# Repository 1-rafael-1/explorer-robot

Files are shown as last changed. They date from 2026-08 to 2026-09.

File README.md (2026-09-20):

# explorer-robot

Evolving project for a tracked robot platform with LiDAR-based
autonomous navigation and sensor-driven obstacle avoidance.

Built in Rust on [Embassy](https://embassy.dev/) for the RP2350 microcontroller.
This iteration builds on hardware experience from [simple-robot](https://github.com/1-rafael-1/simple-robot), adding a
360° spinning LiDAR (COIN-D6), a VL53L0X rangefinder (front-down), ICM-20948 IMU over
SPI, a ST7789 TFT display, and a Grove Vision AI V2 camera module — as much as I can manage on custom PCB hardware. The ultrasonic/servo sweeping sensor array is ditched, and so are the IR sensors.

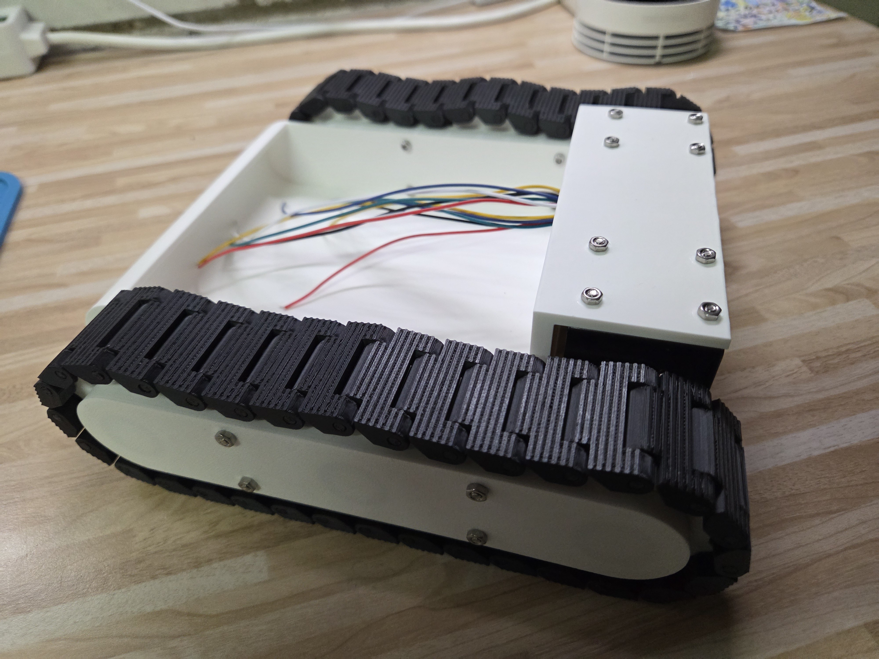
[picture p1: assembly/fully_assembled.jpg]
Fully assembled explorer-robot


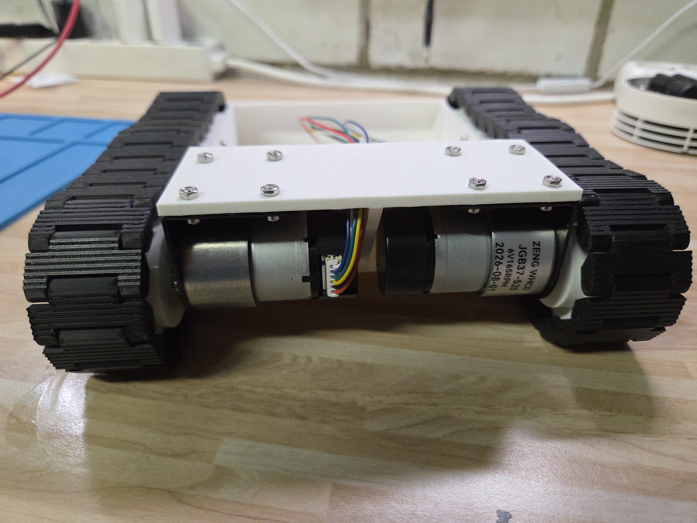
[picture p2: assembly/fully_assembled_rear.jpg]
Fully assembled explorer-robot, rear view


## Status

Active development. Core subsystems (drive, perception, UI, calibration) are
implemented: the LiDAR driver and the Panel and Touch Panel geometry are real,
while the rangefinder and the AI camera remain stubbed or planned.

The big to-dos, in no particular order:

- [x] Make a new chassis to accommodate the new motors and ball bearings.
- [x] Make a D6 lidar driver
- [x] Make an async tft driver
- [x] Integrate the D6 lidar driver into the firmware
- [x] Integrate the tft driver into the firmware
- [ ] Make an async-capable VL53L0X driver and integrate that
- [ ] Make a new schematic adapting from simple-robot
- [ ] Full breadboard demonstrator to see if the firmware is botched
- [ ] Make an async Grove Vision AI V2 driver and integrate that
- [ ] Design a new PCB from that. Depending on how mad I feel, maybe ditch some dev boards in favor of an SMD design.

## Hardware

- **MCU:** Raspberry Pi RP2350B (dual-core Cortex-M33)
- **Motors:** 2× JGB37-520 6V DC with Hall encoders, 165 RPM
- **Bearings:** 12× 6802-2RS (DIN 625; a.k.a. 61802-2RS)
- **Motor driver:** TB6612FNG dual H-bridge
- **LiDAR:** COIN-D6 360° spinning dTOF (core1, buffered UART0 [] power MOSFET, driver integrated, off at boot and powered on demand)
- **AI Cam:** Grove Vision AI V2 (core0, UART1 [] power MOSFET reserved, not yet integrated)
- **Rangefinder:** 1× VL53L0X ToF, front-down (stair/drop detection), on shared I2C0 bus (currently stubbed)
- **IMU:** ICM-20948 9-axis over dedicated SPI bus
- **Display:** ST7789 240×320 Panel driven landscape as a 320×240 framebuffer, on the shared SPI1 bus
- **Input:** Resistive touch panel (XPT2046-class) sharing the display's SPI1 bus
- **Power:** 2S LiPo (8.4V max)

## Assembly

The chassis and running gear are my first CAD design at this level of
complexity. It works as I planned, but I fully expect to find reasons to change,
add, or remove parts as I go. I've printed it in PLA on a 0.4 mm nozzle at
variable layer height with good results — after running the motors for an hour
straight on a riser, nothing looked worn or abraded, there was no PLA dust
anywhere, and all the track pins were still in place.

### Parts required

Purchased:

- 2× JGB37-520 motors (with encoders)
- 2× matching motor brackets (often sold with the motors)
- 12× 6802-2RS ball bearings (6 per track)
- 8× M3 8 mm screws
- 8× M3 40 mm screws
- 16× M3 nuts

Printed:

- 1× chassis main part
- 2× inner track pod parts
- 2× outer track pod parts
- 2× driven sprockets
- 4× freewheeling sprockets
- 6× sprocket holders (one per sprocket)
- 64× track links (32 per track)
- 64× track link pins

### Track assembly

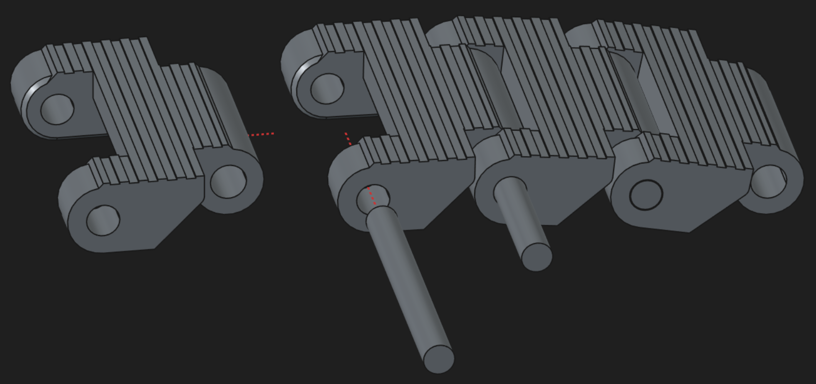
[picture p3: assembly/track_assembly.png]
Track assembly


### Track pod assembly

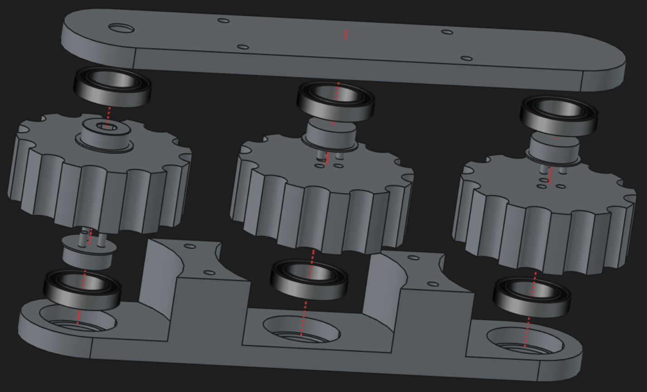
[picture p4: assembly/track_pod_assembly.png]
Track pod assembly


### Overall assembly

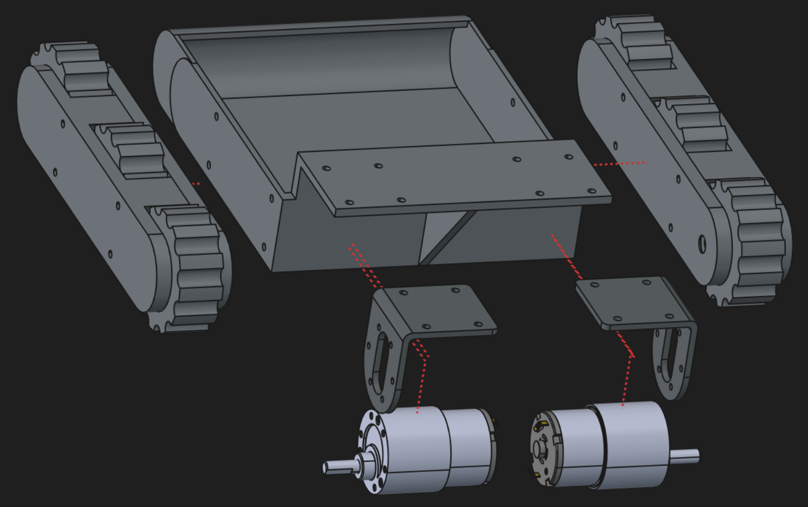
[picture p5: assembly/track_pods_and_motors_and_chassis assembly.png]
Track pods, motors and chassis


### Assembly tips

- The driven sprocket's D-shaft hole is a very tight fit on the motor's D-shaft.
  Push the sprocket onto the shaft at least once before final assembly — the real
  assembly later will be much easier.
- The bearings have to be pressed into the pod shells with some force. Keep them
  even, since everything is a tight fit. I used a rubber mallet, gently.
- After each step, check that the sprockets turn freely in the pod without
  scraping. The screws — combined with the pressure needed to fit the D-shaft —
  can introduce enough strain that something ends up slightly off, causing wobble
  and scraping. It does fit in the end, but takes a little patience.
- The 8 mm screws can be fiddly to get in — use tweezers. After a few minutes of
  colorful cursing they'll go in.

## License

MIT

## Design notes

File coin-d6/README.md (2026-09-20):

# coin-d6

An async driver for the COIN-D6 360° spinning dToF LiDAR. It's `#![no_std]` and
HAL-agnostic: it owns an `embedded_io_async::Read + Write` UART and a
synchronous power `OutputPin`, feeds bytes through a pure decoder, and exposes
scans either one revolution at a time or aggregated over several revolutions.

## Public API

- **`Point`** — one LiDAR return: `angle_deg` (degrees), `distance_mm`
  (`Option<NonZeroU16>`, millimetres — `None` means no return), `intensity` (0–255).
- **`Scan<const N = 512>`** — one revolution (native 400 points at 0.9°, with
  512-point capacity), plus `len`.
- **`Reduction<const BUCKETS>`** — a by-angle reduction's output: up to `BUCKETS`
  fused buckets with its own bucket count, independent of the consumed scans'
  capacity, plus `len`.
- **`Decoder`** — pure byte-stream decoder (checksum, `AA 55` header resync,
  ring-start delimiting, angle interpolation).
- **`aggregate`** — fuse several scans by angle with a validity gate and a
  median/mean reducer, returning a `Reduction<BUCKETS>`.
- **`angle_correction_deg`** — the vendor's distance-dependent angle correction.
- **`Warmup`** — pure warm-up settle state machine (settle/plateau/exhaust from
  per-revolution point counts), configured by **`WarmupConfig`** and reporting a
  **`WarmupOutcome`**.
- **`NATIVE_POINTS`** — the steady-state point count per revolution (400).
- **`CoinD6`** — owns the UART and power pin; lifecycle is `power_on` →
  `start` → `warm_up` (optional) → `read_scan`/`read_aggregated` → `stop` →
  `power_off` (or `release` to hand the peripherals back).

## Wiring

| Signal | RP2350 pin |
|---|---|
| LiDAR TX → MCU RX | GPIO 13 |
| LiDAR RX ← MCU TX | GPIO 12 |
| Power MOSFET gate (active-high) | GPIO 15 |
| GND | GND |
| +5 V | 5 V rail |

> These are the standalone example's pins. The robot integration uses different
> pins (LiDAR RX on GPIO1, MOSFET on GPIO26); see the repository `CONTEXT.md`.

## Tests

The pure decoder, post-processing, and warm-up stages are host-tested. The
workspace's
`.cargo/config.toml` defaults to the bare-metal `thumbv8m` target, so pass the
host target explicitly:

```sh
cargo test -p coin-d6 --features std --target x86_64-unknown-linux-gnu --tests
```

## Running the example

The bare-metal example uses the `probe-rs` runner from
`coin-d6/.cargo/config.toml`:

```sh
cargo run -p coin-d6 --example example --release
```

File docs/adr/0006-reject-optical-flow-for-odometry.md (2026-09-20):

# Reject optical flow as an odometry sensor

Bounding track slip requires a ground-relative speed source, and a downward
optical-flow sensor was the obvious candidate. Every available part fails this
chassis's requirements. Mouse-class sensors (ADNS-3080/9800, PMW3360/3389) need a
**2.1–2.6 mm** standoff, forcing a ground-hugging skirt that defeats the ground
clearance the chassis is being designed to gain. The one dedicated near-field
part, PixArt's **PAA5100JE**, is specced for **15–35 mm** and loses tracking as
soon as the surface departs that window — constantly, on grass, rock and stair
edges. The drone family (**PMW3901**, 80 mm–infinity) does survive the clearance,
but optical flow measures *angular* velocity, so converting to ground speed
divides by the standoff: a rover whose ground distance varies continuously gets a
proportionally wrong speed, and the signal collapses on low-texture ground at that
range. We therefore drop optical flow and rely on the 2D LiDAR scan matcher as the
absolute odometry reference, with dead reckoning between corrections.

## Considered Options

- **Mouse-class optical flow** (ADNS-3080 2.40 mm, ADNS-9800 2.4 mm, PMW3360
  2.2–2.6 mm, PMW3389 ≈2.1 mm) — rejected: requires the low skirt we are trying to
  avoid.
- **PixArt PAA5100JE / PAA5100JE-Q** (15–35 mm) — rejected: the 35 mm ceiling is
  exceeded by ordinary terrain, and the standoff must be near-constant.
- **PMW3901 drone family** (80 mm–infinity) — rejected: standoff-proportional
  scale factor makes it wrong on varying ground distance, and it needs texture.
- **24 GHz Doppler radar** (OmniPreSense OPS243-A ~$224, uRAD Doppler ~€190,
  Infineon BGT24LTR11-based) — the correct technology for this clearance budget if
  ground-relative speed is ever needed, since it measures range-rate directly and
  ignores standoff. Held as a documented reserve, not adopted: it yields only
  longitudinal speed, gives no heading, and costs two orders of magnitude more
  than an encoder.

## Notes

- Research: `.scratch/optical-flow-sensor-working-range.md`.
- The reserve is worth revisiting only if bench data shows longitudinal track slip
  dominating the error budget; it does not address yaw.

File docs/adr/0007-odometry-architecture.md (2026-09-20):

# Odometry: dead reckoning corrected by tilt-gated scan-to-map matching

The robot needs a continuous **Pose** in the **World Frame** from onboard sensing
alone, and every available source is individually inadequate. Encoders give good
longitudinal speed but **infer direction from the motor command** (the PWM input
counter cannot decrement) and slip 10–30 % in skid-steer turns. The ICM-20948's DMP
gives trustworthy roll/pitch but `Axis6` yaw drifts without bound. A single 2D
spinning LiDAR is the only source of absolute `(x, y, yaw)` correction, but
scan matching assumes a flat world, and terrain tilt violates that. The decision is
to fuse them by role: **encoders and IMU predict, and a scan-to-map matcher supplies
a low-rate absolute pose update admitted only while the robot is level.** The matcher
aligns each spin against an incrementally built occupancy grid (**Odometry Grid**)
grown from the robot's own scans and never persisted. Tilt is handled by *per-point*
masking rather than rejecting whole spins, because tilt is bearing-dependent —
forward beams dip under pitch while lateral beams stay horizontal — so discarding the
whole scan would throw away usable geometry. Dead reckoning ships first, with the
matcher added behind it.

## Considered Options

- **Encoder-only dead reckoning** — rejected: yaw from the track differential is
  unusable on a skid-steer platform.
- **Encoders + IMU only** — rejected: drift is unbounded. Adequate per leg, not per
  mission, and not a base to build mapping on.
- **Scan-to-scan matching** — rejected: cannot bound drift and cannot re-acquire after
  a tilt-gate closure, which is precisely what the stairs/slope use case needs.
- **Scan-to-map with whole-scan tilt gating** — rejected: on a slope it discards the
  near-field and lateral geometry that is still valid.
- **Full SLAM with loop closure (Cartographer-class)** — rejected: needs a 64-bit CPU
  and 16 GB RAM.
- **Adding a ground-relative sensor** — see ADR-0006; optical flow rejected, Doppler
  radar held as a reserve.

## Consequences

- Pose becomes a first-class state module (**Pose State**) in the documented lock
  order, because the drive intents, gap analysis, UI and mission layer all read it.
- The **Odometry Grid** is session-local: no flash persistence and no pre-load. The
  robot seldom powers up in the same pose it powered down in, so a persisted grid
  would need re-anchoring anyway.
- The magnetometer (`Axis9`) is enabled as a **weak, high-variance absolute yaw
  observation** — the only absolute heading available while the gate is closed — with
  a runtime fallback to `Axis6` when mag data is bogus, extending the existing
  start-up-time `effective_mode` downgrade.
- Encoder covariance becomes **state-dependent**, inflated by commanded turn rate and
  by unpowered states where the sign is unknown.
- The scan matcher runs on core1 and the EKF on core0; tuning parameters are
  centralised and documented in `.scratch/odometry/spec.md` so they can be adjusted
  without re-deriving the design.

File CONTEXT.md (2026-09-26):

# Explorer Robot — Domain Glossary

> This glossary records the canonical terms for the explorer-robot v3 firmware. It is a living document — update it whenever a term is resolved during design or implementation.

## Hardware

- **Weight Distribution** — Motors (~400g) at the rear, battery (~100g) at the front. Remaining components (PCB, LiDAR, rangefinder) biased forward to achieve roughly centered center of mass for even track pressure and stable climbing.
- **Track** — Left or right side of the robot. Each track has three sprockets: rear drive sprocket (motor-coupled, toothed), middle road wheel (weight-bearing, smooth), and front idler (tensioner, smooth). Rear drive keeps the bottom track run in tension under load, maximizing traction and preventing track bunching.
- **Motor** — A single JGB37-520 6V 165RPM DC motor with hall encoder. Two motors (one per track).
- **Motor Driver** — The TB6612FNG dual H-bridge chip. Controls direction (via direct GPIO) and speed (via PWM) for both motors. One standby pin enables/disables the driver.
- **Encoder** — Two-channel (A/B) hall encoder on each JGB37-520 motor. Counts 1320 pulses per output shaft revolution (165:1 gear ratio) via PWM input mode. Only one channel is read, so direction is inferred from the motor command rather than measured from the A/B phase.
- **IMU** — ICM-20948 9-axis inertial measurement unit (accelerometer, gyroscope, magnetometer). Connected via dedicated SPI bus (CS, SCK, MOSI, MISO).
- **LiDAR** — COIN-D6 360° spinning dTOF LiDAR on dedicated UART0 (core1): TX on GPIO12, RX on GPIO1, with an active-high low-side power MOSFET (IRLS44N) on GPIO26. Emits continuous scan data at a native 0.9° resolution (400 points per revolution) with distances in millimetres, over UART at 230400 baud 8N1 with a start/stop command protocol. Driven by the `coin-d6` workspace crate on core1, and powered only while a mode needs it.
- **AI Cam** — Grove Vision AI V2 on-device ML camera module (Himax WiseEye2), reserved on dedicated UART1 (core0) with its own power MOSFET (IRLS44N). Not yet integrated — pins reserved only.
- **Rangefinder** — VL53L0X time-of-flight laser rangefinder. Single unit, front-down (angled downward for stair/drop detection), on the I2C0 bus. No XSHUT sequencing needed — single device at default address. The 360° LiDAR covers forward/lateral/rear arcs, so only the downward-facing sensor is retained (currently stubbed for development).
- **Panel** — The 2.8″ 240×320 (320×240 landscape) ST7789 TFT display module and its resistive touch layer, sharing a full-duplex SPI1 bus. The robot's only input and output surface: the Display draws, the Touch Panel senses.
- **Display** — The Panel's drawing surface: a 320×240 landscape RGB565 framebuffer rendered by the ST7789 controller.
  _Avoid_: OLED, screen
- **RGB LED** — Common-cathode RGB LED. Indicates battery state (green → yellow → red) and obstacle alerts (flashing red).
- **Battery** — 2S LiPo (twin 18650, 8.4V max). Placed at the front to counterbalance the rear-mounted motors (~400g combined). Voltage read via ADC. Motors compensated to 6V target.
- **Standby Pin** — Direct GPIO that enables/disables the TB6612FNG motor driver. Active high.

### LiDAR

- **Spin** — One full 360° revolution of LiDAR returns: 400 points at the native 0.9° resolution.
- **Snapshot** — A single-revolution capture, as returned by `read_scan`.
- **Point** — One LiDAR return, `{ angle_deg, distance_mm, intensity }` (bearing in degrees, range in millimetres as an `Option` — `None` means no return — and return strength 0–255).
- **Ring-start** — The packet flag (`T == 1`, the low bit of the `CT` byte) that delimits the start of a new spin.
- **Validity ratio** — The minimum fraction of aggregated spins that must report a valid (`distance_mm.is_some()`) sample at an angular bucket for that bucket to be kept; otherwise the bucket is emitted as a no-return.
- **Bin representative** — The single LiDAR return chosen to stand for all native samples that fall within one angular bucket during aggregation. It is the *nearest valid return*, so coarsening a bucket never hides a closer obstacle (not the first sample, strongest return, or a mean).
- **Warm-up** — The post-`start` phase during which revolutions are discarded until the rotor reaches steady-state speed. Settling is proxied by the per-revolution point count stabilising near the native 400 (as opposed to plateauing below it, or exhausting a spin budget).
- **Enabled** — The LiDAR's lifecycle state: `Off`, `Warming`, `Streaming` or `Failed`. A mode enables the sensor when it needs perception and disables it when it is done; at most one mode needs perception at a time, and the enabled sensor serves data to every reader.
- **No Return** — A bin for which no valid range was measured. It is not an obstacle, and it must not be read as a clear angle: gap selection never treats it as navigable.
- **Front Sector** — The angular window about dead ahead that the Coast-and-Avoid stop test sweeps: ±45° by default, with a 30 cm stop threshold.
- **Room Scan** — The operator-initiated mode that renders live Spins as a radar on the Display, for verifying the LiDAR and surveying a room. It does not drive.

### Touch

- **Touch Panel** — The 2.8″ 240×320 SPI panel's resistive touch layer, and the robot's sole operator input. Its controller IC is unmarked; the XPT2046/TSC2046-class protocol is an assumption confirmed on the bench.
- **Touch Sample** — One raw reading from the touch panel: X, Y, and the two Z (pressure) channels in unfiltered 12-bit counts.
- **Touch Calibration** — The mapping from raw touch counts to screen pixels, measured at the panel's corners.
- **Reference Calibration** — The vendor reference board's raw endpoints, shipped as `Calibration::REFERENCE` for first bring-up only; not measured on this robot's panel.
- **Measured Calibration** — This robot's panel raw endpoints, measured from the corner calibration targets during bring-up and recorded as `Calibration::MEASURED`.
- **Calibration Target** — A marked point on the display at a known screen coordinate, touched during calibration to pair a raw reading with that coordinate.
- **Touch Pressure** — A position-independent resistance proxy derived from a touch sample's two Z channels, distinguishing a firm press from a light one; a proxy, not a calibrated physical pressure.
- **Touch IRQ** — The touch controller's active-low pen-down interrupt line (`PENIRQ`).
- **Shared SPI Bus** — One SPI bus carrying more than one device, arbitrated by chip select and per-device configuration (the Display and Touch Panel share SPI1).

### Menu

- **Menu Entry** — One entry of the Panel's menu tree, carrying its label, the screen it opens, and the screen the header Back returns to. An entry is a submenu, a Procedure, or a screen. Entries are named, not positioned, so reordering a menu cannot change what an entry starts.
  _Avoid_: option, row, index

## Architecture

- **Core0** — Runs the orchestrator, drive subsystem, encoder reader, UI (Display, Touch Panel, RGB LED), IMU (SPI0), I2C bus (VL53L0X rangefinder), flash storage, and the main event loop.
- **Core1** — Runs the LiDAR task: the `coin-d6` driver, its on-demand power lifecycle, and the spin-to-point-cloud mapping.
- **Orchestrator** — Central event loop. Waits for events from the system event channel and dispatches them: calibration events → initialization module, obstacle/battery events → behavior handlers, lifecycle events → UI subsystem, sensor events → logged or forwarded. Pure routing — no domain logic.
- **Event System** — Typed, multi-producer single-consumer event channel (capacity 64). Sensor tasks and input tasks raise events; the orchestrator consumes them. The seam between producers and consumers.
- **Behavior Handler** — A module under `task/behavior/` that reacts to specific event types. Domain logic lives here — obstacle fusion (perception atomics + EmergencyBrake interrupt), battery state updates, obstacle avoidance completion. Called by the orchestrator.
- **Task Spawn Order** (core0) — Tasks are spawned in dependency order: orchestrator → battery → rgb_led → motor_driver → encoders → drive_queue_executor → drive → panel → vl53l0x_stub → imu → flash_storage → testing → autonomous_mode → startup. Core1 runs only the LiDAR task.

### Message Passing

Three data flow patterns coexist, chosen by latency requirements:

- **Event bus** — Semantic events (obstacle detected, button pressed, calibration loaded) flow through `Events` channel → orchestrator → handlers. Used for state changes that multiple consumers may care about.
- **Direct channels** — High-frequency sensor data (encoder pulses, IMU orientation) flows point-to-point via dedicated `Channel`s directly into the drive subsystem, bypassing the event bus. Avoids event channel congestion.
- **Perception atomics** — `LIDAR_OBSTACLE` and `FLOOR_DROP` atomic booleans provide lock-free reads on the hot path. The `LiDAR` task writes the obstacle flag and the floor-drop stub writes the floor-drop flag; read by autonomous modes and the UI without acquiring a mutex.

## Driving

The `drive` module tree owns all motion control. Commands flow through a thin dispatch that routes to control modules. Two public entry points: `send_drive_command` (queue a command) and `send_drive_interrupt` (preempt).

- **SetTracks** — The primary motor command. Sets left and right track speeds (-100 to +100). Calibration and voltage compensation are applied before PWM output.
- **Drive Distance** — A `DriveAction` that commands travel of a specified distance (straight or curved arc) using encoder feedback with optional IMU correction. Completes when target is reached or an interrupt preempts it.
- **Rotate Exact** — A `DriveAction` that commands in-place rotation to a target angle using IMU feedback. Completes when the angle is reached within tolerance.
- **Drift Compensation** — Encoder-based correction that equalizes left/right track speeds to prevent veering. Handled by higher-level intents (distance, rotation) via IMU heading correction and encoder feedback.
- **Ramp-Down** — Progressive speed reduction as a distance or rotation command approaches its target. Prevents overshoot.
- **Voltage Compensation** — Scales PWM duty cycle to maintain 6V effective motor voltage as battery drains: `compensation = 6.0 / battery_voltage`.

### Drive Subsystem Internals

- **Drive Queue** — A builder (`DriveQueueBuilder`) that accumulates `DriveCommand` steps and submits them for sequential execution. A single `drive_queue_executor` task runs one queue at a time, emitting one queue-level completion.
- **Drive Task** — The main control loop (`drive()`). Polls active intents, steps idle when no intent is active, and handles interrupts. Selects over the command queue and the interrupt signal.
- **Intent** — A state machine that owns a specific motion behavior — rotation, distance drive, brake/coast settle, or idle. Each intent is an `ActiveIntent` variant carrying its controller state and completion flag. Commands that complete instantly (e.g., `Differential`) are not intents; they are fire-and-forget.
- **Dispatch** — The thin seam between the drive command queue and the control modules. Routes incoming `DriveCommand` envelopes, handles standby wake-up, and executes `IntentTeardown` descriptors on completion or interrupt. Owns no per-intent knowledge.
- **IntentTeardown** — An enum declaring what sensor streams must be stopped when an intent completes or is interrupted. Each `ActiveIntent` returns its teardown descriptor; the dispatch executes it. Keeps the dispatch thin — it knows to stop sensors but not which specific sensors each intent required.
- **InterruptKind** — An enum (`EmergencyBrake`, `Stop`, `CancelCurrent`) that specifies how the drive subsystem preempts the active intent. Sent via `send_drive_interrupt`.
- **EmergencyBrake** — An `InterruptKind::EmergencyBrake` sent when the `LiDAR` reports an obstacle or a floor drop is detected. Causes immediate active motor braking, cancels the active intent, bumps the command epoch, and drains queued commands. Mode-agnostic — dispatched unconditionally on either the obstacle edge or the floor-drop edge.
- **Epoch** — A monotonic counter incremented on each interrupt. Queued commands stamped with an old epoch are discarded when dequeued, preventing stale commands from executing after an interrupt.

## Odometry

- **Odometry** — The self-contained estimate of the robot's pose and its change, from onboard sensing alone; any reference it aligns against is one it built itself.
  _Avoid_: position tracking, dead reckoning (that is the uncorrected subset)
- **Pose** — The robot's position and heading `(x, y, yaw)` in the World Frame.
  _Avoid_: position, location
- **World Frame** — The reference frame that pose is expressed in; its origin is the robot's pose at the start of a mission. Convention: `+x` forward, `+y` left, `yaw` counter-clockwise positive, degrees at the API boundary and radians internally.
- **Dead Reckoning** — Propagating pose from a motion model (encoders plus IMU) with no absolute correction, so error grows without bound.
  _Avoid_: inertial navigation
- **Scan Matching** — Estimating the rigid transform `(Δx, Δy, Δθ)` that best aligns one LiDAR spin with a reference, either the previous spin or the Odometry Grid.
  _Avoid_: registration, alignment
- **Odometry Grid** — The occupancy grid that scan matching aligns spins against. It is built from the robot's own scans and anchors the estimate to the world, bounding drift rather than merely slowing it.
  _Avoid_: map (reserved for the mission's map of the environment)
- **Scan Plane** — The plane swept by the LiDAR rotor over one spin. It is fixed to the chassis, so it tilts with the robot.
- **Flat-World Assumption** — The premise that every spin slices the world at a constant height and orientation. It is what makes 2D scan matching well-posed, and what terrain tilt violates.
- **Tilt Gate** — The IMU-driven admission test that admits or discards a scan-match pose according to roll and pitch.
- **Drift** — Unbounded growth of pose error under dead reckoning.
  _Avoid_: accumulated drift (that names the gap-analysis term **Leg Drift**)
- **Pose Confidence** — The system's uncertainty in the pose, raised by track slip and by tilt-gate closures.
- **Pose State** — The module holding the fused pose and its uncertainty, with lock-free mirrors for hot-path readers.
- **Estimation Error** — The difference between the robot's believed pose and its true pose. The error that odometry work is measured by.
- **Execution Error** — The difference between the robot's true pose and the pose the drive was commanded to reach, caused by slip, calibration and ramp-down overshoot. Odometry does not fix it.
- **Closure Error** — The pose discrepancy measured after the robot returns to its starting point, expressed as a fraction of the path length. The mission-level accuracy figure.

## State Modules

Lock order (documented in each module): **power → calibration → perception → motion → activity**

- **Power State** — Battery level (0–100%) and voltage. Accessed via `power::try_get_battery_voltage()` for hot-path readers.
- **Calibration State** — Motor calibration factors (`left_factor`/`right_factor`), IMU calibration status, distance calibration factor. Persisted to flash.
- **Procedure** — A long-running, operator-started, stoppable unit of work: a test mode, a calibration, or a drive mode. Identified by the Menu Entry that starts it.
  _Avoid_: job, task (that names an embassy task), mode (that names an autonomous mode)
- **Activity State** — What the robot is currently doing: a Procedure, recorded by its identity, or the boot flow, with a small progress snapshot — phase and percent. Written by the producers, read by the touch UI, which is the only thing that draws. A finished Procedure is presented as a Result Report.
- **Result Report** — The status screen for a finished Activity State: it names the outcome, gives the reason on failure, and holds until the operator deliberately leaves it. A successful Procedure may return on its own; a failed one never does.
- **Perception State** — Dual-path architecture for obstacle detection. *Lock-free path:* the `LIDAR_OBSTACLE` and `FLOOR_DROP` atomic booleans for hot-path reads. *Detailed path:* a mutex-protected optional cloud (`lidar-cloud`'s `Cloud` — 360 one-degree slots of an optional distance in centimetres, with a sequence counter). The old zero-distance sentinel is retired: a slot is `None` for no return.
- **ObstacleSource** — Enum (`Lidar` only, for now) carried by `ObstacleDetected` events. Identifies which sensor triggered the detection. Only the LiDAR raises obstacle edges: the rangefinder is a stair/drop sensor and raises its own `FloorDropDetected` edge, which is never an obstacle. A rangefinder variant returns only if several rangefinders are ever added for obstacle detection.
- **ChangeDetected** — Enum returned by perception setters: `NoChange`, `ChangedToDetected`, `ChangedToCleared`. Enables edge-triggered reactions to obstacle state transitions without polling.
- **Motion State** — Track speeds (left and right, -100 to +100) with lock-free atomic mirrors for high-frequency readers.

## Autonomous Modes

- **Coast-and-Avoid** — Drive forward until the obstacle flag signals detection. Brake, back up, random-angle turn (±45°–180° via nanorand), resume forward. The flag comes from the LiDAR's Front Sector test; the mode reads only the pre-computed boolean, and refuses to run if the LiDAR cannot be enabled. Simple, reliable.
- **Attempt Straight Line** — User sets target distance (100–1000 cm). The LiDAR point cloud is analyzed for navigable gaps; the widest gap within the forward cone (±60°) is chosen. The robot rotates toward the gap center, drives a leg, and repeats. IMU heading used for drift correction. Completes when target distance is reached or no forward path exists. *(Deferred — UI integration pending.)*

### Gap Analysis

- **Gap** — A contiguous angular arc in the LiDAR point cloud where no obstacle return is within threshold (default 30 cm). A valid gap has sufficient width at its constriction depth, is flanked by obstacles, and lies within the forward cone.
- **Constriction Depth** — The minimum distance across the angles that make up a gap. Determines how far the robot can safely travel through that gap.
- **Leg** — One rotate-then-drive maneuver through a chosen gap. The leg length is the constriction depth minus a safety margin, or the remaining target distance if shorter.
- **Leg Drift** — The signed sum of deviation angles across all legs of a gap-following run. Later legs apply a correction toward the ideal straight line.
  _Avoid_: Accumulated Drift (that names the estimation concept **Drift**)
- **Correction Angle** — The gap midpoint angle that would cancel the current leg drift (= `-drift`). The gap closest to this angle is preferred.

## Calibration

- **Motor Calibration** — Per-track speed multipliers (`left_factor`/`right_factor`, range `(0.0, 1.0]`). The faster track is always the reference at 1.0; the slower track gets a factor < 1.0. Computed by running each track at fixed PWM and measuring encoder pulses.
- **Distance Calibration** — Single factor (range 0.5–2.0) mapping encoder pulses to real-world centimeters. Corrects for surface friction and tire wear.
- **IMU Calibration** — Magnetometer hard/soft iron calibration and motor interference compensation (`MagCalibration`). Gyroscope and accelerometer bias are handled internally by the ICM-20948 DMP.
- **Boot Sequence** — On `Initialize` event, the initialization module sends individual `GetData` commands to flash storage for motor, IMU, distance, and IMU flag calibration data. Each response raises a `CalibrationDataLoaded` event. When all four are received, the UI shows the main menu.
- **Flash Storage** — `sequential-storage` + `embedded-storage-async`. Saves motor calibration (2× f32 as `MotorCalibration`), distance factor (1× f32), and magnetometer calibration flags (`ImuCalibrationFlags`) to dedicated FLASH_STORAGE region (last 8KB of flash).

## Development Practices

- **No HIL (Hardware-in-the-Loop) rig** — The project has no automated hardware test rig. All tests that require physical hardware (sensors, motors) must be done manually on the target RP2350 board. `cargo check` and `cargo clippy` are the automated compile-time gates; the `coin-d6` crate additionally has host-side decoder/aggregation/warm-up tests run with `cargo test -p coin-d6 --features std --target x86_64-unknown-linux-gnu --tests` (the explicit host target is required because the default build target is `thumbv8m.main-none-eabihf`). Do not write `#[cfg(test)]` unit tests — they cannot exercise the real hardware and offer no value over compile-time checks. The `testmode` embassy tasks under `task/testmode/` serve as manual HIL verification procedures.
- **Hardware-tests crate** — `hardware-tests` is a workspace member for standalone, breadboard-scale HIL checks that exercise one or two sensors in isolation (e.g. the LiDAR→TFT radar), running as their own embassy binaries under `examples/`. Distinct from the in-firmware `testmode` tasks: these run outside the robot firmware, on a breadboard, rather than inside the running robot.
- **Testable logic in workspace crates** — Calculations that are hardware-independent (decoders, state machines, controllers, estimators) belong in `#![no_std]`, HAL-agnostic workspace crates that can be host-tested behind a `std` feature, as `coin-d6` does. This is the desired pattern. Older firmware code still performs such calculations inline, where they can only be verified by driving the robot, and extracting them is a standing refactoring opportunity.

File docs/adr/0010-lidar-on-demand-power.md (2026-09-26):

# Power the LiDAR on demand, not continuously

The COIN-D6 is powered down whenever no mode needs it, rather than left spinning from
boot. The sensor is the most expensive part on the robot and a spinning dTOF head is a
wear item; keeping it running through motor tests, calibration and idle trades its life
for nothing. The cost is a warm-up wait at every mode entry and a power lifecycle to get
right.

**Status:** accepted. The leased ownership model originally recorded here is superseded by ADR-0017: the LiDAR task owns its power lifecycle, and a mode enables and disables the sensor rather than holding a lease. The bullets below state the enable/disable model.

**Considered Options**

- **Spin from boot and always.** Simpler and with no warm-up stall, and the earlier
  firmware took this for granted. Rejected on part life and power draw.
- **Pre-warm when the operator opens the relevant menu, or keep a grace period after a
  mode exits.** Rejected for now: it couples menu navigation to sensor state for a wait
  that is legible on screen. Revisit if the stall proves annoying in use.

**Decision**

- A persistent core1 task owns the driver for the whole runtime and exposes
  `enable()` / `disable()` / `status()`. A mode enables the sensor when it needs perception and
  disables it when it is done; the task owns power, warm-up, retries and streaming (ADR-0017).
  At most one mode needs perception at a time, so the enabled sensor serves every reader.
- `enable()` runs `power_on()` → `start()` → `warm_up()` → streaming. A `start()` failure
  is tolerated; warm-up is the real proof that data flows.
- Warm-up is bounded by a wall-clock timeout at the call site, because the driver has only
  byte-count watchdogs. On timeout the task power-cycles and retries a bounded number of
  times before reporting `Failed`.
- `disable()` stops the device, deasserts the power pin, and clears stale state: the stored
  cloud becomes `None`, the obstacle flag is cleared, and a cleared `ObstacleDetected`
  edge is raised if the flag had been set.
- Coast-and-Avoid enables the LiDAR on entry and **refuses to start** if the sensor cannot be
  brought up, rather than driving with only the downward rangefinder for obstacle sense.
- The LiDAR is off at boot; motor tests, IMU tests, calibration and idle never power it.

**Consequences**

- Entering Coast-and-Avoid or Room Scan may wait several seconds while the rotor reaches
  steady state; the screen shows the warming state so the wait does not read as a hang.
- Consumers must treat an absent cloud as unknown, not as an empty room: a `None` snapshot
  means the sensor is off or not yet warmed.
- A stopped sensor can leave an obstacle flag behind, so `disable()` carries the
  obligation to clear it in the same step.
- `disable()` is one-way and not owner-scoped, so a leave delivered after another mode has
  enabled the sensor powers it down under that mode; the window is small and accepted rather
  than guarded (ADR-0017).
- The power MOSFET stays wired even though it is now load-bearing rather than optional.

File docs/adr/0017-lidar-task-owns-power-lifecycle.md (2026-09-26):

# The LiDAR task owns its power lifecycle; a mode enables and disables the sensor

The COIN-D6 is powered on demand (ADR-0010), and its driver is owned for the whole runtime
by a single core1 task. Access to *that* task's service was leased and ref-counted, so that
two modes could hold the powered sensor at once. But only one mode ever needs perception at
a time — the panel is modal, and the test-mode and autonomous-mode slots each admit one mode
— so the reference count only ever papered over a teardown race, while forcing every consumer
to thread a token, to reproduce the bring-up's failure and retry semantics in its own docs,
and to reason about an acquisition generation. This replaces the lease with a one-way command.

**Status:** accepted. Supersedes the ownership paragraph of ADR-0010.

**Considered Options**

- **Keep the lease and its ref count.** Rejected: there is never a second holder, so the count
  is machinery for a case that does not exist; its one real effect is to hide an ordering
  accident in the panel rather than fix it.
- **Let an orchestrator (the UI) be the single enable/disable writer.** Rejected: the panel is
  just one channel that may need to command the sensor, and it would have to learn every
  mode's end, including the modes that finish on their own.
- **Let the task derive need from the system's state.** Rejected: to know when to power down it
  must count consumers, which is the lease again, and it couples the task to the procedure
  model.

**Decision**

- A mode enables the sensor when it needs perception and disables it when it is done. The
  commands are one-way on a dedicated `Channel`, as motor and flash commands are; the task
  owns power, warm-up, retries, streaming and power-off, and keeps the driver for the runtime.
- Readiness is observed through the lock-free `status()` — `Off`, `Warming`, `Streaming`,
  `Failed`. The task does not signal; callers poll.
- Bring-up is edge-triggered: a failed attempt holds at `Failed` until a `Disable` clears it,
  and the clear publishes `Off` so a caller can observe the reset land. A duplicate `Enable`
  is ignored, so a caller cannot spin retries by polling. `enable()` releases a latched failure
  itself — `Disable`, wait for `Off`, then `Enable` — so a caller that re-enters a mode after a
  failure starts a fresh bring-up instead of wedging on an ignored `Enable`.
- The data path is unchanged: the enabled sensor publishes its cloud, its obstacle flag and
  its `ObstacleDetected` edge, and serves every reader.
- `Lease`, `AcquireError::Busy`, the acquisition generation and both reply channels are
  deleted.

**Consequences**

- A departing mode's `Disable` can land after an arriving mode's `Enable`, powering the sensor
  off under a mode that has just enabled it. The window is the departing task's teardown
  (brake and driver-disable, a few hundred milliseconds) and is reached only by navigating
  three screens inside it. Room Scan widens the same window in miniature: its helper converges
  on the screen's latch when it is next scheduled, so a leave just before a new mode enables
  can be delivered as a `Disable` after that `Enable` — a scheduler delay rather than a
  teardown. Both are accepted rather than guarded, because a guard is either a count or an
  identity token, which is the lease this decision removes. Revisit if a bench or field report
  ever shows the sensor dropping under an active mode.
- There is no compile-time reminder to hand the sensor back, so a forgotten `Disable` keeps
  the sensor powered; a bench run shows that immediately.
- This rests on *at most one mode needs perception at a time* (the glossary's **Enabled**),
  the same invariant the panel and the mode slots already enforce.

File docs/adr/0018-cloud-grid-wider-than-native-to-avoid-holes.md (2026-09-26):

# The cloud grid is wider than the sensor's native resolution, so empty slots usually mean measured no-returns

The cloud is a fixed 360-slot grid of one-degree bins (ADR-0011), while the COIN-D6 emits at a
native 0.9° / 400-point resolution (ADR-0002). That mismatch is deliberate. Binning assigns a
sample to a slot by angular containment, and it reports a slot as `None` both when the slot
received no sample and when its samples were all no-returns. A grid at or under the sensor's
inter-sample spacing therefore manufactures empty slots, and an empty slot is indistinguishable
from a measured no-return — the one ambiguity ADR-0011 exists to prevent. 1.0° is chosen because
it is strictly wider than the sensor's sample spacing, so a slot is normally sampled and a `None`
slot usually means "measured, no return" rather than an unsampled hole. It is not an absolute
guarantee — the per-point angle correction noted below can still spread adjacent returns past a
boundary — only a strong default.

**Status:** accepted.

**Considered Options**

- **Narrow the grid to the native 0.9° (400 slots).** Rejected: at ~400 points per revolution
  the native spacing *is* 0.9°, the same as the slot width, so any phase drift empties slots.
  The rotor settles into 397–403 points (`WarmupConfig::settle_tolerance`), i.e. spacing
  0.893°–0.907°; at the slow end the spacing exceeds the width and slots go empty. An empty slot
  bins to `None`, exactly as a measured no-return does, so gap selection would see phantom blind
  spots (making `is_clear` wrongly conservative) and the radar would draw phantom dots. A
  sub-native grid is worse still: it adds empty slots by construction.
- **Carry the native points with no grid (a variable-length cloud).** Not pursued: it would
  avoid both holes and collisions and preserve the true bearings, but it turns the cloud from a
  fixed slot array into a point list, so the radar widget's neutral slot type and the
  slot-index geometry in the Front Sector and gap rules all change. It is a larger change than
  this decision needs, and the grid's bounded loss is acceptable.

**Decision**

- The cloud stays a 360-slot, one-degree grid (`lidar_cloud::SLOTS`, `SLOT_WIDTH_DEG`). The
  firmware reduces onto it explicitly (`resolution_deg = SLOT_WIDTH_DEG`) rather than taking the
  driver's native 0.9° default.
- The width is chosen to be **wider than the largest inter-sample angular gap** at the settled
  rotor speed, so angular-containment binning normally finds at least one sample per slot and a
  `None` slot is usually a *measured* no-return rather than an unsampled hole.
- The occupancy is not absolute: the driver applies a distance-dependent angle correction to each
  point, so two adjacent samples at very different ranges can be spread past a 1.0° boundary and
  leave the slot between them unsampled. The width is chosen to keep this rare, not to exclude it.
- Binning stays by containment with the nearest-valid-return collapse (ADR-0002): where two
  native samples fall in one slot the farther is dropped — a bounded, safety-conserving loss
  that can never hide a closer obstacle.

**Consequences**

- 1.0° is the *minimum safe* width for the settled band, not an arbitrary round number. Any move
  to the native 0.9° reintroduces holes and must not be made without re-deriving the occupancy
  estimate.
- The occupancy depends on the rotor settling near 400 points before streaming: a revolution
  carrying fewer than 360 points could leave even 1.0° slots empty. The warm-up phase
  (ADR-0010, ADR-0017) is what holds this.
- The cloud is ~11% coarser than the sensor (1.0° vs 0.9°) and collapses ~40 of 400 samples per
  revolution. That resolution cost is accepted in exchange for a `No Return` that is usually
  measured rather than a sampling artefact.
- The max-gap figure (360/397 ≈ 0.907°) is derived from the settle band, not yet measured on
  hardware. Revisit if a bench measurement of consecutive point-angle deltas (taken after the
  driver's angle correction) shows the true largest gap reaching 1.0°, or if full 360° coverage
  per revolution does not hold (a seam gap could empty a slot at any width). Narrow only with
  margin, never to the nominal 0.9°.

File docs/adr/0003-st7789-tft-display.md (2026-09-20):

# ST7789 TFT on dedicated SPI1, replacing the SSD1306 OLED (RP2350B variant)

The SSD1306 128×64 OLED was replaced with a 240×240 ST7789 TFT driven by the
hand-rolled `st7789-async` driver (ADR-0001). The TFT needs a dedicated
write-only SPI bus plus five GPIOs, which the RP2350A pin budget could not
provide without collisions against the IMU, I2C0, LiDAR, and AI-cam pins — so
the firmware moved to the RP2350B variant for GPIO headroom.

**Status:** partly superseded by ADR-0008. The RP2350B variant move, the panel choice, the typography and the layout constants still stand; the dedicated write-only bus, the absence of a chip select and the text-only contract are superseded, because the panel now shares a full-duplex SPI1 bus with the touch controller and renders graphics. See also ADR-0009 for the retired rotary encoder. The panel itself is 240×320, driven landscape as a 320×240 framebuffer; the 240×240 figure in this ADR described the retired square text working area, not the glass.

**Decision**

- Move the main crate to the RP2350B variant (`rp235xb`) for GPIO headroom;
  `hardware-tests` and the `st7789-async` examples stay on `rp235xa`.
- Drive the TFT over a dedicated, write-only **SPI1** (`Spi::new_txonly`,
  64 MHz), leaving the IMU untouched on SPI0 and I2C0 free for the VL53L0X only.
- The display module has **no CS pin**, so there is no `ExclusiveDevice` and no
  `embedded-hal-bus` dependency: the bare `Spi` is wrapped in an
  `embassy_sync::Mutex` (the IMU's pattern) to satisfy `SpiDevice`.
- Pin assignment (all RP2350B-only, no collision with the 0–28 map):
  SCK=GPIO30, MOSI=GPIO31, DC=GPIO32, RST=GPIO33, BLK=GPIO34. SPI1 TX on
  DMA_CH6.
- Keep the display seam: the `DisplayAction` channel and `display` task contract
  are unchanged; only the driver internals move from I2C/SSD1306/`BinaryColor`
  to SPI1/ST7789/`Rgb565`.
- Text-only, monochrome white-on-black for now; `TextStyle` Normal/Bold maps to
  `FONT_9X15` / `FONT_9X15_BOLD`.
- Typography: 9×15 font, 17 px/line → 14 lines × 26 chars
  (`DISPLAY_LINES = 14`, `MAX_LINE_LEN = 26`).
- Retain the scrolling logic (scroll-offset state, `max_system_info_scroll`,
  menu windowing) even though every screen now fits; it stays dormant and
  future-proofs longer lists.
- The display task owns BLK (backlight on) and RST (hardware reset sequence)
  before driver `init`.

**Consequences**

- The framebuffer is 115,200 bytes of static `.bss` (`ConstStaticCell`), fine
  against the 520 KB SRAM; no `memory.x` change.
- Full-frame `flush()` is ~15 ms at 64 MHz — acceptable for a menu, so the
  partial-redraw path from the driver example is not needed.
- Orientation defaults to `Deg0` with `Bgr` colour order; the colour order is
  panel-specific and is confirmed on first bring-up.

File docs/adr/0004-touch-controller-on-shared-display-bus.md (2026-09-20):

# Touch controller on the shared display SPI bus

The 2.8″ panel's resistive touch layer is being added as a secondary input
alongside the rotary encoder. Its controller has to share one SPI bus with the
ST7789 display, but the two devices want very different clock speeds — 64 MHz
for the display and ~200 kHz for the touch controller — so a single bus must be
arbitrated and reconfigured per device. This is developed and proven on the
bench only; the robot's own display bus is left untouched.

**Status:** accepted; its deferred robot migration has since landed as ADR-0008, which reopens ADR-0003 as this ADR predicted. The bench findings below (protocol confirmation, PENIRQ arming, RGB colour order, measured calibration) carry over to the robot unchanged.

**Considered Options**

- **Hand-rolled arbiter:** a bespoke lock/select/reconfigure routine around the
  bare `Spi`. Dropped in favour of the proven library device, which already
  handles cancellation and flush ordering.
- **`SpiDeviceWithConfig`:** `embassy_embedded_hal::shared_bus::asynch::spi::SpiDeviceWithConfig`
  over an async `Mutex`, one handle per device. Chosen.

**Decision**

- Per-device configuration is mandatory, not optional: the display runs at
  64 MHz and the touch controller at ~200 kHz, so the bus must be reconfigured
  for whichever device is selected.
- Arbitration and reconfiguration come from
  `embassy_embedded_hal::shared_bus::asynch::spi::SpiDeviceWithConfig` rather
  than a hand-rolled arbiter. Each transaction locks the async bus `Mutex`,
  applies the device's config through the HAL's `SetConfig`, asserts that
  device's chip select, and flushes the write. It is cancellation-safe, so an
  aborted await cannot leave the bus locked with a stale configuration.
- Both devices use **Mode 3** (`CaptureOnSecondTransition` + `IdleHigh`) and
  differ only in clock, so reconfiguration changes the frequency alone. Mode 0
  is the documented fallback if the panel misbehaves.
- This sits in tension with ADR-0003, which specified the robot display as a
  dedicated, **write-only** SPI bus with **no chip select**. Sharing a bus in
  the robot would instead require a full-duplex bus with a driven chip select,
  contradicting that decision. The robot migration is deliberately deferred and
  would reopen ADR-0003.
- Scope is bench-only: the `hardware-tests` coexistence example shares SPI0 on
  the rp235xa board. No robot firmware changed.
- The touch IC's markings are sanded off, so the XPT2046/TSC2046-class protocol
  is an assumption, not a verified fact. That includes the Z (pressure)
  channels, which the reference design never exercised; the assumption is
  confirmed empirically on the bench by the `touch_probe` example.
- Pre-integration check: the display is assumed ST7789-compatible because the
  existing async driver works on the test panel. A cheap 2.8″ panel can be an
  ILI9341 clone with a similar-but-not-identical init sequence, so the display
  controller identity must be confirmed before the robot display is migrated.
- Filtering boundary: the driver returns raw counts and does no filtering. The
  example applies the `moving_median` crate caller-side, and `moving_median` is
  **not** a dependency of the driver crate.

**Bring-up outcome (bench)**

- The `touch_probe` example confirmed the XPT2046/TSC2046-class framing on the
  bench: raw X/Y track the finger, and both Z channels respond (`z1 > 0` and
  `z2 > z1` on a touch), including `Z2`, which the reference design never read.
- The controller only asserts `PENIRQ` after a conversion has selected
  auto-power-down, so the driver performs one discarded read to arm it before
  waiting on the edge. Without that, `wait_for_touch` blocks forever on a cold
  start.
- `PENIRQ` is level-sensitive, not an edge per touch, so `wait_for_touch` waits
  on `wait_for_low` rather than a falling edge. After a low level that yields no
  valid sample it waits for the line to return high before awaiting the next low
  edge; a bare level wait would re-read immediately while the line stayed low
  (noise, or a release mid-read) and busy-spin SPI/CPU. A falling-edge wait is
  unusable here because the arming conversion is itself what drives the line low,
  so the edge would already have passed.
- The panel is RGB-ordered: `ColorOrder::Bgr` swaps red and blue on this panel,
  so the examples use `Rgb`.
- Calibration measured from the four coexistence corner targets is recorded as
  `Calibration::MEASURED`: raw endpoints `x1=3810, x2=160, y1=276, y2=3844` for
  the 320 × 240 framebuffer in the coexistence orientation. The measurement
  procedure is documented in the `hardware-tests` README.

**Consequences**

- The touch driver stays HAL-agnostic and depends only on an async `SpiDevice`,
  so it is equally usable on a dedicated or a shared bus.
- The `touch_coexistence` example proves both devices arbitrate cleanly on one
  bus, which is the evidence the deferred robot migration will build on.
- The `Calibration::default` constants are reference-only values from the
  vendor's board, not our panel's calibration; for this panel they have been
  superseded by `Calibration::MEASURED`, measured on the bench.
- Migrating the robot to this panel would reopen ADR-0003 and is a separate
  follow-up, outside this effort.

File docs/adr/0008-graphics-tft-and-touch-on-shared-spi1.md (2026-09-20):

# Graphics TFT and touch on the robot's shared SPI1 bus

The robot's display moves from a dedicated, write-only SPI1 bus with no chip select
(ADR-0003) to a shared, full-duplex SPI1 bus carrying both the ST7789 panel and the
resistive touch controller, arbitrated with `SpiDeviceWithConfig` so each device locks the
bus, applies its own clock, and asserts its own chip select. This reopens ADR-0003 and
completes the robot migration ADR-0004 deliberately deferred; the bench-only scope of
both is retired.

**Status:** accepted. Supersedes the display-bus and text-only parts of ADR-0003.

**Considered Options**

- **Keep the dedicated write-only display bus and give touch its own SPI bus.** Rejected:
  the panel module shares one set of SPI pins between its display and touch layers, and a
  second bus costs five pins against a robot that has to keep expansion room.
- **Move the panel to SPI0's high quad and the IMU to SPI1.** Rejected: SPI0's high pins
  are a clean full-duplex group, but the IMU's move would collide with the motor, RGB and
  LiDAR pins and force a bigger reshuffle for no gain.

**Decision**

- One full-duplex SPI1 carries both devices in Mode 3, differing only in clock: 64 MHz for
  the display, ~200 kHz for the touch controller. Per-device configuration is mandatory,
  not an optimisation.
- Arbitration comes from `SpiDeviceWithConfig`, as proven by `touch_coexistence`, rather
  than a hand-rolled arbiter.
- The bus mutex is `CriticalSectionRawMutex`. The bench examples used `NoopRawMutex`, which
  is only sound for a single executor and priority.
- Pins, chosen fresh because nothing was wired yet: SPI1 SCK/MOSI/MISO = GPIO 42/43/44,
  TFT CS/DC/RST/BLK = 41/45/46/47, touch CS/IRQ = 38/39, with the battery ADC staying on
  GPIO 40 and the LiDAR and I2C0 assignments unchanged.
- The display's 240 × 240 text-mode contract is retired with the bus decision; the panel
  becomes a graphics device owned by one task.

**Consequences**

- SPI1 MISO is forced to GPIO 44: the only MISO-capable SPI1 pins are GPIO 40 and 44, and
  40 is the battery ADC.
- The bus needs a receive DMA channel, so `DMA_CH7` joins `DMA_CH6` in the `DMA_IRQ_0`
  binding group.
- The display no longer has a CS pin, so `embedded-hal-bus` enters the firmware's
  dependency set and the `NoCsSpiDevice` adapter is deleted.
- The former display pins (30–34) and the rotary footprint (22–24) return to the spare
  pool.
- The panel's touch pins and its display pins are one bus, so a panel fault and a touch
  fault are no longer independent.

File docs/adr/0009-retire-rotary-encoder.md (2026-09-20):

# Retire the rotary encoder: touch is the sole operator input

The EC11 rotary encoder is removed from the robot's design and its firmware, and the
resistive touch panel becomes the only operator input. The decision is deliberate beyond
convenience: the panel can render a control for every action, and the encoder's three GPIOs
are wanted elsewhere, but it leaves the robot with no input that works when the UI task is
hung or the panel is dead.

**Status:** accepted

**Considered Options**

- **Keep the encoder as a fallback input alongside touch.** Rejected: two input paths means
  two UI models, and the encoder's turn/press/hold vocabulary was already the reason the
  menu logic was shaped around a hardware gesture rather than a screen.
- **Add a hardwired emergency-stop button on the motor driver's standby pin.** Rejected for
  now: a kernel-level stop is a different safety property from a touch Stop, but the
  operator's reachable power switch plus the touch Stop on every running screen is judged
  sufficient. This is an accepted risk, not an oversight — revisit if the robot ever runs
  in a space where the operator cannot reach it.
- **Keep the encoder wired but unused.** Rejected: dead hardware with live pin claims is
  worse than either keeping or removing it.

**Decision**

- `src/task/control/`, `Ec11Pins`, the PIO1 SM3 quadrature initialisation,
  `RotaryDirection`, the `Events::Rotary*` and `UiEvent::Rotary*` variants, the
  `handle_rotary_*` handlers and `next_menu_index`'s rotary parameter are all deleted.
  PIO1 keeps only its RGB LED state machines.
- Every action the encoder offered has a screen affordance: tap replaces turn-and-press,
  header Back replaces hold-to-back, and a touch Stop is added to every running screen.
- Because the hold gesture was the only way out of some running procedures, tests that had
  no stop API (`turns`, `straight_drive`, `arc_drive`) gain stop signals.
- GPIO 22, 23 and 24 return to the spare pool, reserved for the future rangefinder
  round-robin.

**Consequences**

- Input now depends on the panel initialising. The display task's existing
  display-offline behaviour keeps the robot running, but it runs uncommandable.
- The UI's input vocabulary is pointer-shaped (tap, press, drag) rather than
  device-shaped, which is what let the menu logic move into a host-testable crate.

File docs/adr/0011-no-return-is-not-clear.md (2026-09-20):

# A no-return bin is neither an obstacle nor a clear angle

The LiDAR point cloud stores each one-degree bin as an explicit `Option<f32>` rather than a
`0.0` sentinel, and the two consumers that read it interpret "no return" in opposite,
deliberate ways: a bin with no return is not an obstacle, and it is not a clear angle
either. The old sentinel made a dropout a *drivable* angle, which is the one reading a
blind spot must never have.

**Status:** accepted

**Considered Options**

- **Keep `0.0` as the sentinel.** Rejected: it makes "no data" indistinguishable from a
  distance, and it forces every consumer to remember which meaning applies.
- **Carry the driver's native `Option<NonZeroU16>` millimetres into the cloud.** Rejected:
  it halves the memory, but it pushes millimetre-to-centimetre conversion into every
  consumer instead of one boundary.
- **Treat a dropout as clear, as the old gap analysis did.** Rejected: the lidar returns
  no reading for a black or specular surface as readily as for open space, so "clear" would
  mean "drive toward the thing we could not see".

**Decision**

- The cloud is 360 bins of `Option<f32>` in centimetres; `None` is no return, and the
  millimetre-to-centimetre conversion happens at the driver-to-firmware boundary.
- The obstacle test ignores `None` bins: a dropout cannot phantom-brake the robot.
- Gap selection treats `None` as not clear: a blind spot can never extend a navigable gap.
- Both rules live in the host-testable `lidar-cloud` crate, with the two behaviours named
  and tested rather than implied.

**Consequences**

- The obstacle test and the gap test deliberately give opposite answers to the same input.
  That is the point, and a reader who "fixes" the inconsistency will reintroduce the
  hazard.
- Gap-following navigation becomes more conservative: an absorbent surface at range reads as
  an obstacle rather than as an opening.

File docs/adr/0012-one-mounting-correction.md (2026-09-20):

# One mounting correction, owned by the LiDAR cloud crate

The COIN-D6 sits in the robot's mount rotated half a turn from the direction the robot
faces, so bearings must be rotated 180° exactly once between the driver and the glass. The
cloud crate applies that rotation when it maps a spin into slots, which makes slot zero dead
ahead and lets the Front Sector and the gap analysis read slots directly. The radar widget
is therefore a neutral consumer: it plots the slot order the bench radar example drew, and
carries no mounting correction of its own. Applying the rotation in both places cancels it,
which draws the room inverted and pushes a dead-ahead return off the bottom edge of the
Panel.

**Status:** accepted.

**Considered Options**

- **Correct in the radar widget and leave the cloud in native bearings.** Rejected: the stop
  test and the gap analysis read slots, so slot zero must already be dead ahead for the
  safety logic; a display-only correction would leave the obstacle rule reasoning in native
  bearings.
- **Keep both corrections as the status quo.** Rejected: they compose to a full turn, so the
  radar disagrees with the bench example about which half of the screen is forward.
- **Split the rotation, half in each place.** Rejected: 180° does not divide into two
  meaningful halves, and a split would make both consumers carry a correction that neither
  can be read alone.

**Decision**

- The mounting rotation lives once, in the LiDAR cloud crate, which maps native bearings to
  slots with slot zero dead ahead. Its direction of application to native bearings is that
  crate's contract and is host-tested there.
- The radar widget plots the neutral slot convention and applies no mounting correction:
  slot zero is drawn at the top of the Panel and slot numbers increase clockwise on the
  glass, matching the bench radar example for the same scene.
- The direction is bench-derived, not asserted from the code: it is confirmed on the robot
  when the LiDAR is mounted, and an inverted room means the cloud's offset sign is wrong,
  not that the widget needs a compensating adjustment.

**Consequences**

- A consumer that plots slots, or reasons in slots, applies no correction. Converting the
  other way is the cloud crate's inverse, and belongs there with it.
- The earlier statements that increasing slots run counter-clockwise — in the cloud crate's
  documentation, in the widget's documentation and in the parent spec — are superseded by
  the bench-matched visual.
- Compensating elsewhere silently re-inverts the radar, so the convention is written in both
  crates' documentation and pinned by a widget test that asserts the drawn position of the
  first slots.
- The parent spec's Room Scan acceptance item (a plausible room, the same way up as the
  bench) becomes the check that keeps this decision honest.

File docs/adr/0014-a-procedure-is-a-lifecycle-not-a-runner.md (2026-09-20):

# A Procedure is a lifecycle the producers call, not a runner they hand a body to

Nine producers — six test modes and three calibrations — each repeated the same six steps:
arm the stop, publish the activity, phase the percent and detail, record the terminal
outcome, release the single-active slot, raise the completion event. Two of them repeated
the stop latch's four forwarding functions verbatim. A single runner that every producer
hands a body to is the obvious collapse, and it is wrong here.

**Status:** accepted.

**Considered Options**

- **One runner all nine producers pass a body to.** Rejected: it would need roughly as many
  parameters as the variance it absorbs. Distance calibration's lifecycle outlives its task
  and is driven from the value-entry screen across a `begin`/`commit`/`abort` sequence; the
  magnetometer is an eight-state body with its own phase results; three producers publish no
  terminal outcome and raise no event; three publish a terminal outcome only on failure; the
  two families claim different slots and raise different events. The deletion test fails:
  the complexity reappears as runner parameters.
- **Collapse only the verbatim stop-latch duplication and leave the rest.** Rejected: the
  repetition beyond the latch is real and is what makes a new Procedure a many-file edit.
- **Move the lifecycle into a host-testable crate.** Rejected: its whole content is embassy
  channels, statics and a critical-section mutex, so a crate would have no pure behaviour
  behind it — a seam with nothing to test.

**Decision**

- A Procedure's lifecycle lives in one module that the producers call: arm the stop, publish
  the phase and percent to the Activity State, publish the terminal outcome, release the
  single-active slot, raise the completion event. A producer supplies its body and its phase
  words.
- The slot claim and the completion event are parameters of the lifecycle, so each family
  keeps its own.
- Distance calibration and the magnetometer keep their own phases and call the lifecycle
  around them.
- The stop latch keeps its per-family instances, so a stop aimed at a test mode cannot reach
  a calibration.

**Consequences**

- A new Procedure is a body and its phase vocabulary, and the lifecycle around it is written
  once.
- The rule that a finished Procedure is presented as a Result Report has one implementation,
  rather than being re-derived by each producer and again by the Panel.
- A reader looking for "what happens when a procedure stops" finds one module instead of
  nine.
- The lifecycle is firmware behaviour and stays compile- and bench-verified; the display
  policy it feeds is host-testable through the model crate (ADR-0013).

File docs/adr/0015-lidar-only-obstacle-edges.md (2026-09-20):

# Only the LiDAR raises obstacle edges; a floor drop is its own edge

Obstacle detection was described by two producers of one edge. The LiDAR task raised
`ObstacleDetected` from its Front Sector test, and coast-and-avoid raised the same edge from
its own poll — while that poll read the obstacle flag *and* the floor-drop flag together, so
a floor drop was reported to the behaviour handler as `ObstacleSource::Lidar`. The handler
then wrote that boolean back into the perception module and read it out again, which latched
the LiDAR obstacle flag true on a floor drop and made the flag's value depend on the last
event rather than on the sensor. The glossary already said the rangefinder is a stair/drop
sensor and only the LiDAR reports obstacles, so the code contradicted the record.

**Status:** accepted.

**Considered Options**

- **Reshape the coast loop's re-raised edge into a floor-drop-shaped one.** Rejected once the
  facts were checked: the floor drop already raises its own edge, and its handler already
  sets the flag, drives its own indication and brakes. The coast loop's re-raise duplicated
  work that was already done by the producer that owns the measurement.
- **Keep the coast loop's re-raise for safety.** Rejected: the brake it caused was redundant
  — the loop had already braked directly, and the interrupt only cancelled a drive intent
  the mode does not use. What it added was a mislabel, a spurious latch and an extra blink.
- **Keep the handler's write-back as a defensive re-assert.** Rejected: the value it wrote
  was the value it had been handed, so it could only ever overwrite the sensor's truth with a
  stale copy of itself through the event bus.

**Decision**

- The LiDAR task remains the only writer of the obstacle flag. The permission's handler reads
  the flag rather than writing it, so the mutex no longer mirrors the lock-free flag.
- The obstacle event carries an edge, not state: a handler acts on what the state module
  holds.
- Coast-and-avoid raises no edge. It stays a consumer of the LiDAR's Front Sector edge and
  the floor drop's edge, and keeps its own direct brake, which is the only thing that
  actually stops it.
- The dead perception readers, the mirrored fields with no live reader, and the stale
  dead-code allowance hiding a live caller are deleted, with no new allowance added.

**Consequences**

- A floor drop stops the robot and reads to the operator as a floor drop. An obstacle stops
  it and reads as an obstacle. Neither claims to be the other.
- The obstacle flag has one writer, so it cannot be set by anything but the sensor.
- One detection has one brake path, so the drive subsystem is not interrupted twice with
  different latencies for the same event.
- A future obstacle source adds its own edge and its own handler rather than widening this
  one — which is what the reserved rangefinder pins are for.

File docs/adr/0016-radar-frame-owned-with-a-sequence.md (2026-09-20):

# The Room Scan frame crosses the model's seam owned, with a sequence

The Room Scan frame — one optional distance per one-degree slot — was represented three
times: in the perception module's cloud, in the copy the Panel's tick fetched out of the
mutex, and in the model's retained frame. Each tick copied the whole array a second time and
compared it in full to decide whether to redraw, while the cloud's own sequence counter,
which exists to make exactly that decision cheap, was discarded at the seam.

**Status:** accepted.

**Considered Options**

- **The model stores a borrow of the frame.** Rejected: it puts a lifetime parameter on the
  model, on the task's state and on every test, and the model cannot outlive a fetch it does
  not own.
- **The model stores only the sequence; the frame is passed at render time.** Rejected: it
  shrinks the model's retained state by the array's size, but it splits one invariant —
  which frame is on screen — across two calls in two owners. A caller that updates the
  sequence without passing the matching frame freezes the screen silently, and the model has
  no way to detect it. It also makes the radar the only screen whose content does not live in
  the model, while the System Info and status snapshots continue to.
- **Narrow the slot type so the frame is half the size.** Deferred, not rejected: it reaches
  into the cloud crate, the gap analysis and the cloud tests, so it belongs in its own change
  rather than in the ticket that moves the seam.

**Decision**

- The model keeps its frame. It is set with the cloud's sequence as the change token, so the
  redraw decision is a counter comparison and the per-tick copy of the array goes.
- The model continues to own every screen's content, so nothing about which screen is showing
  can disagree with itself.
- The cloud crate keeps learning no firmware types, and the slot convention keeps its single
  owner (ADR-0012).

**Consequences**

- The Panel's tick no longer spends a whole-array copy and comparison per refresh, and the
  sequence counter earns its place.
- A frame reaches the model with its identity attached, so the same frame twice reports no
  change and a new frame always reports one.
- The model's retained state stays the size of one frame. That is the cost of keeping one
  owner for one invariant, and it is small beside the Panel's framebuffer, which is fifty
  times larger and resident regardless.

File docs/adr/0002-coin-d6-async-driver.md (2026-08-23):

# COIN-D6 360° LiDAR: hand-rolled async driver

The COIN-D6 360° spinning dToF LiDAR streams a continuous point cloud over
UART. We chose to hand-roll a `#![no_std]`, HAL-agnostic async driver — owning
the UART and the power-MOSFET pin, feeding bytes through a pure decoder, and
exposing single-revolution and aggregated scans — modelled on `st7789-async`.
The pure decoder, post-processing, and warm-up stages are host-tested so the
framing, aggregation, and settle logic can be validated without hardware.

**Status:** accepted

**Decision**

- Hand-rolled `#![no_std]`, HAL-agnostic async driver in the `coin-d6` workspace
  crate, modelled on `st7789-async`.
- Generic over `embedded_io_async::Read + Write` and a synchronous
  `embedded_hal::digital::OutputPin` for the power MOSFET.
  **Deviation:** the spec named `embedded_hal_async::serial`, but
  `embedded-hal-async` 1.0 has no `serial` module, so the driver uses
  `embedded-io-async` (the standard async serial trait). The example drives the
  sensor with embassy's interrupt-driven `BufferedUart`, which implements those
  traits directly, so no adapter is needed.
- Decoupled `Scan`/`Point` with no knowledge of the robot's point-cloud
  representation; native 0.9° / 400 points, millimetres, with `Scan` sized to
  512 for headroom against slow-spin truncation.
- A pure byte-stream `Decoder` (checksum, `AA 55` header resync, ring-start
  delimiting, angle interpolation incl. wrap, `0xFE`/`0xFF` spin-up skipping)
  plus pure `aggregate` (median/validity gate) and `angle_correction_deg`.
- `aggregate` fuses two orthogonal axes: within a revolution each angular bucket
  collapses to its **nearest valid return** (so coarsening the grid can never
  hide a closer obstacle), while across revolutions buckets are combined by the
  configured median/mean with a validity gate.
- An optional rotor warm-up phase (`CoinD6::warm_up`) driven by a pure `Warmup`
  state machine: the per-revolution point count proxies rotor speed, and the
  phase settles, plateaus, or exhausts according to a `WarmupConfig`. The pure
  decoder, post-processing, and warm-up stages are host-tested via
  `cargo test -p coin-d6 --features std --target x86_64-unknown-linux-gnu --tests`.
- The passive concurrency model: no spawned tasks; the caller awaits
  `read_scan`/`read_aggregated`/`warm_up`.
- UART read errors (overrun, break, framing, parity) are treated as recoverable
  resync rather than fatal: `embedded_io::ErrorKind` cannot distinguish them
  (embassy maps every UART error to `Other`), so the driver resyncs the decoder
  and keeps reading instead of surfacing `Error::Uart`.
- The distance-dependent angle correction transcribed verbatim from the vendor
  SDK and gated by `Config::angle_correction` (flagged for hardware validation).
- A portable data-starvation watchdog for the `Error::Timeout` variant — byte
  count, end-of-stream, and missed chunks from UART errors all count toward it;
  the driver is executor-agnostic and has no wall clock, and the example can add
  a wall-clock timeout at the caller level.

**Consequences**

- The driver lives in `coin-d6/`, decoupled from `embassy-rp`, so it can be
  host-tested in isolation and reused later.
- Because UART read errors resync rather than fail, a caller that pauses after
  `power_on()` (for example a delay) no longer crashes on the resulting RX
  overrun — the driver re-synchronises and continues.
- Robot firmware integration — rewiring core1 and the 400/0.9° `LidarPointCloud`
  — is a separate follow-up.

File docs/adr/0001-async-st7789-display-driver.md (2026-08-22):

# Async ST7789 display driver, hand-rolled instead of mipidsi

The SSD1306 OLED is being replaced with an ST7789 TFT over SPI. We chose to
hand-roll an async driver — own the SPI bus and data/command pin, borrow a
caller-allocated framebuffer, and expose `embedded_graphics::DrawTarget` plus an
async `flush` — rather than use `mipidsi`, which is blocking and write-through.
Async redraw needs a framebuffer + `flush()` shape, and
`embedded_graphics::DrawTarget::draw_iter` is synchronous (you cannot `.await`
inside it), so mipidsi's write-through `DrawTarget` is the wrong architecture.
mipidsi's DCS init sequence and orientation mapping remain the reference.

**Status:** accepted

**Considered Options**

- **mipidsi (blocking):** proven init sequence, but no async and write-through. Dropped.
- **`mipidsi-async`:** an empty stub (`// TODO`), so not a real option.
- **Hand-rolled async driver:** owns `embedded-hal-async` SPI and the DC pin,
  borrows a caller-allocated framebuffer, implements `DrawTarget` and an async
  `flush`; DCS init copied from mipidsi as reference. Chosen.

**Consequences**

- The driver lives in the `st7789-async/` workspace member, decoupled from
  `embassy-rp`, so it can be bench-tested in isolation and reused later.
- Pixels are encoded big-endian RGB565 into the framebuffer by the driver's
  `DrawTarget` implementation, so `flush` can DMA the buffer verbatim.

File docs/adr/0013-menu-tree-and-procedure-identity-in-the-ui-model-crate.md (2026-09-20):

# The Panel's menu tree and Procedure identity live in the touch UI model crate

The model crate owns the Panel's screens but not the Procedures behind them, so a Menu
Entry's label, its destination and the screen Back returns to were each written down in
the firmware as well — a label three times, a parent relation four, and a Procedure's name
in five parallel tables. The firmware also had no way to ask the model for a screen, so it
moved the Panel by fabricating a pointer tap at a rectangle it had computed itself.

**Status:** accepted.

**Considered Options**

- **Keep the screen tree in the firmware and treat the crate as a widget library.** Rejected:
  the duplicate tables were the defect, not a side effect of it.
- **Let the model own outcomes as well as screens, driving every transition from them.**
  Rejected: the model would have to learn drive outcomes and sensor state, which are not
  screen facts, and the actuators' policy would move away from the actuators.
- **Add only the command-level entry point and leave the titles where they were.** Rejected:
  the five title tables are what makes adding a Procedure a many-file edit.

**Decision**

- One enumeration names every Menu Entry and carries its label, the screen it opens, the
  screen Back returns to, and whether it ends only on an explicit stop. Nothing else states
  a label or a parent.
- An entry is a submenu, a Procedure, or a screen, so the distinction is in the type and the
  Activity State cannot name a submenu where a Procedure belongs.
- The model resolves where a finished Procedure lands, from the entry's identity.
- The firmware asks the model for the screen it wants; it never fabricates input.
- The Activity State records a Procedure by identity rather than by a parallel enumeration.

**Consequences**

- Adding, renaming or reordering a Menu Entry is one edit, and reordering is a compile-time
  question rather than a silent change of which Procedure a tap starts.
- Where a finished Procedure lands is a screen-tree fact, so it is expressible through the
  model's public interface and therefore host-testable without the Panel.
- The model accumulates domain vocabulary — Procedures, their labels, their parents — but no
  hardware knowledge, so the crate stays HAL-free.
- The placeholder screen vocabulary, which existed only to be overwritten before it was
  drawn, is deleted rather than maintained.

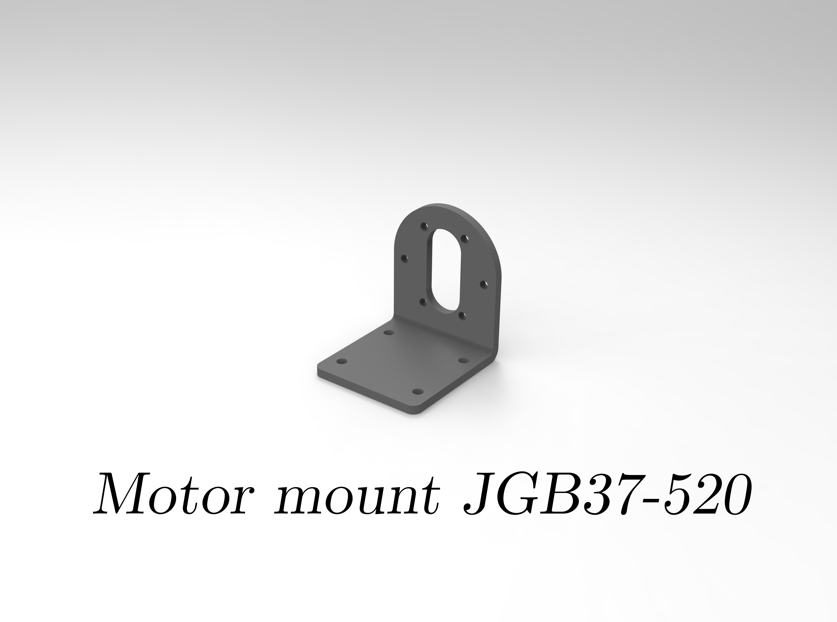
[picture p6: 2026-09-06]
cad files/assets/motor-mount-for-jgb37-520-1.snapshot.9/Fixtures_render.png

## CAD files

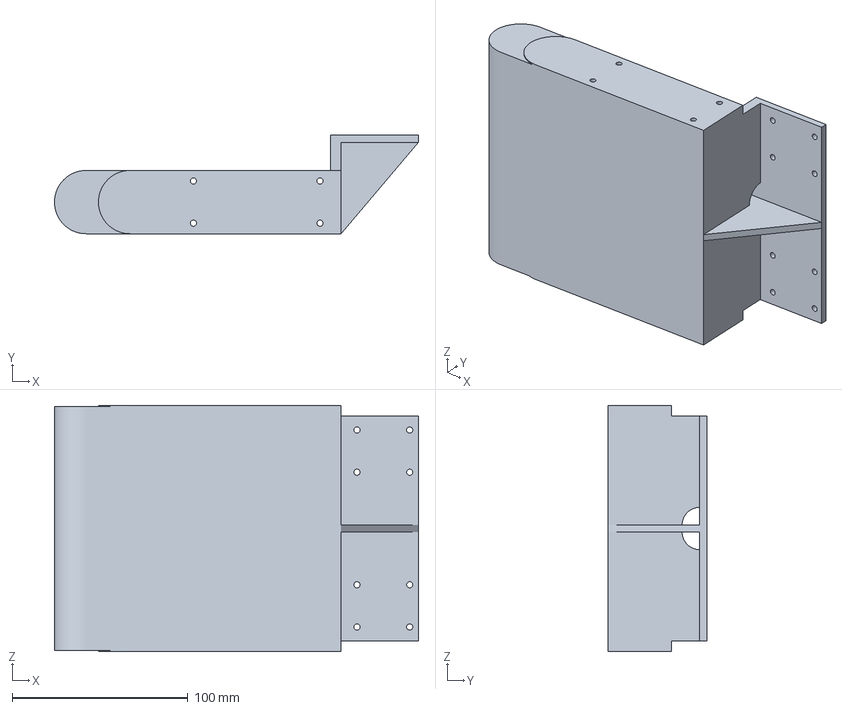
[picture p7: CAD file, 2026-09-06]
cad files/print files/chassis-main.3mf
207.0 x 56.0 x 140.0 mm

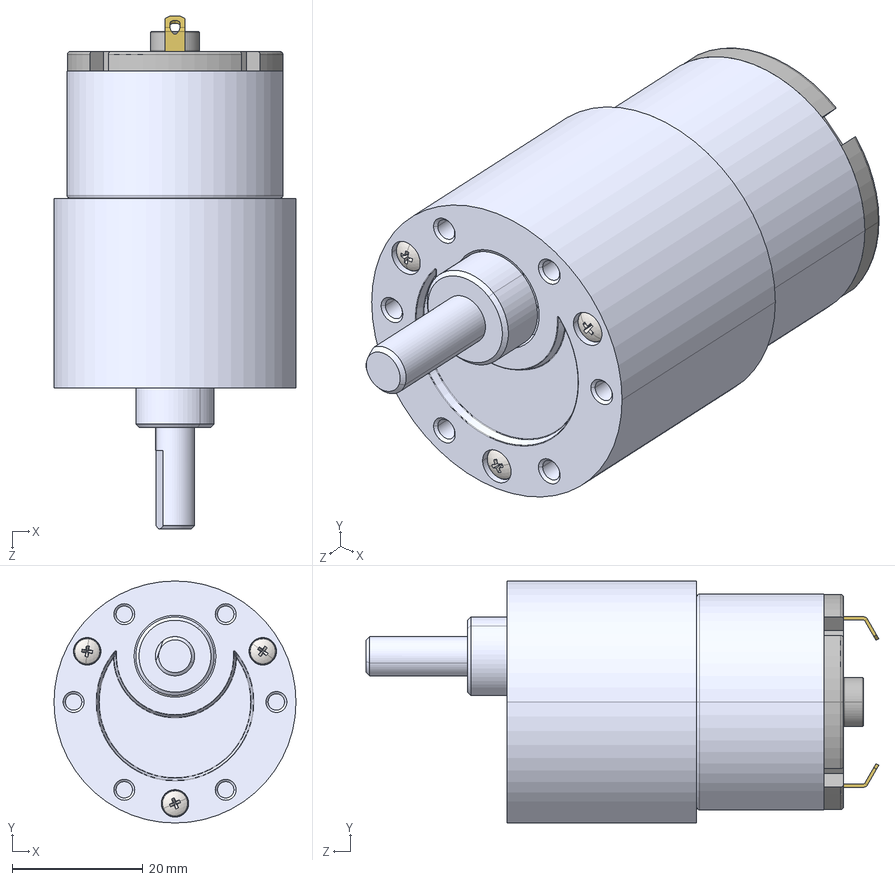
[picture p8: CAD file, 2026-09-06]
cad files/assets/jgb37-520-1.snapshot.4/JGB37-520.STEP
37.0 x 37.0 x 78.4 mm
GEARED BODY, MOTOR, JGB37-520
DC MOTOR, JGB37-520
MOTOR SHAFT, JGB37-520
SHAFT COUPLER, JGB37-520
COUPLING BRACKET, GEARED BODY TO DC MOTOR, JGB37-520
PLASTIC COVER, DC MOTOR, JGB37-520
CONNECTION, DC MOTOR, JGB37-520 x 2
pan cross head_am_B18.6.7M - M2 x 0.4 x 25 Type I Cross Recessed PHMS --25N x 3

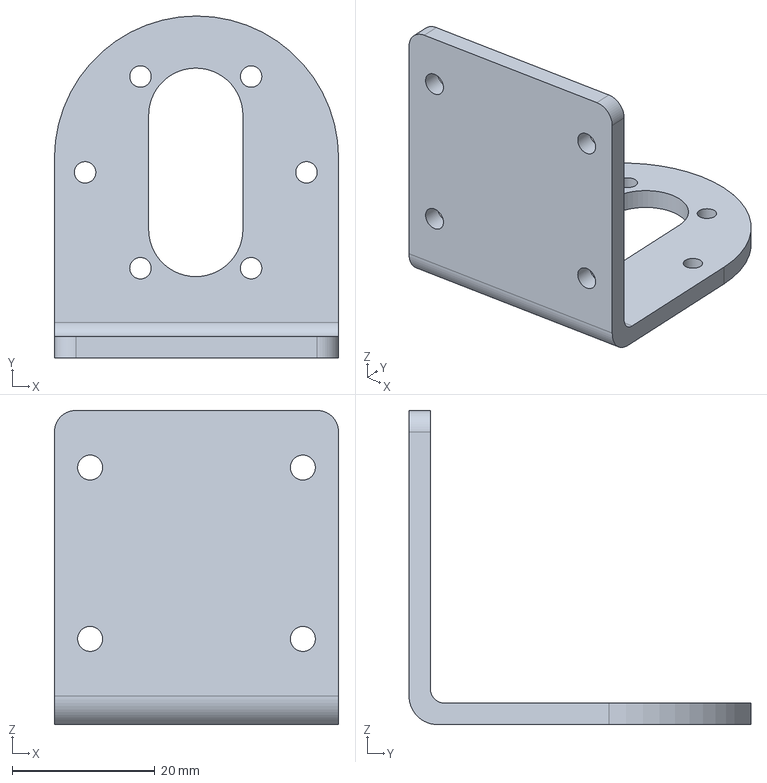
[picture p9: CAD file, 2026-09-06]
cad files/assets/motor-mount-for-jgb37-520-1.snapshot.9/Motor mount.stp
39.8 x 47.9 x 44.0 mm

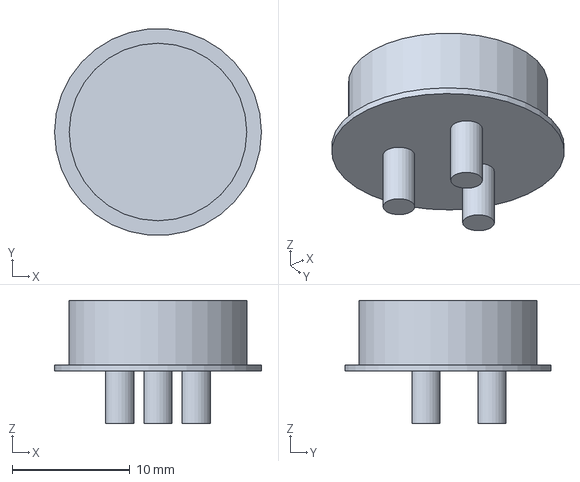
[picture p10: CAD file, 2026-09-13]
cad files/print files/sprocket_holder.3mf
17.6 x 17.5 x 10.5 mm

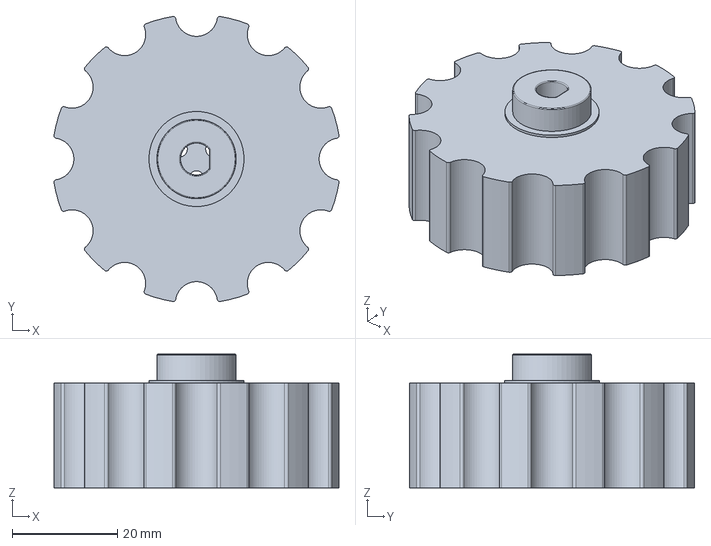
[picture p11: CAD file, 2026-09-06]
cad files/sprocket_driven.FCStd
54.3 x 54.3 x 25.5 mm

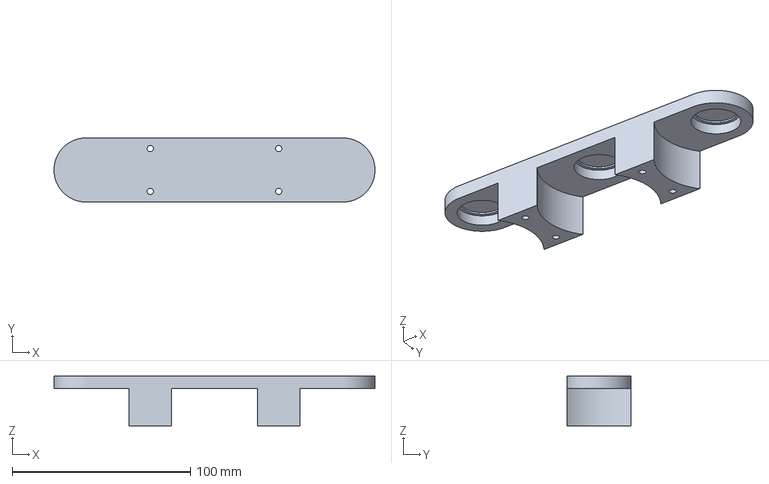
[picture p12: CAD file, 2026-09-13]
cad files/print files/track pod-outer.3mf
180.0 x 36.0 x 28.0 mm

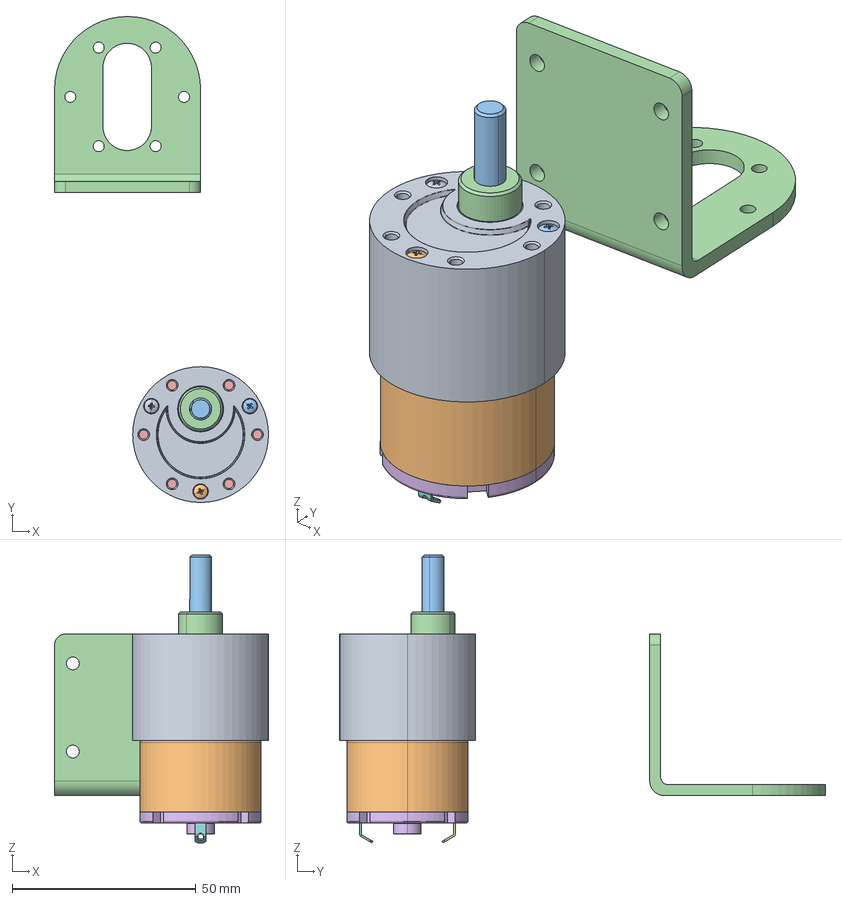
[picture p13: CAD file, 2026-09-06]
cad files/bracket.FCStd
58.3 x 132.4 x 78.4 mm
GEARED BODY, MOTOR, JGB37-520
DC MOTOR, JGB37-520
MOTOR SHAFT, JGB37-520
SHAFT COUPLER, JGB37-520
COUPLING BRACKET, GEARED BODY TO DC MOTOR, JGB37-520
PLASTIC COVER, DC MOTOR, JGB37-520
CONNECTION, DC MOTOR, JGB37-520
CONNECTION, DC MOTOR, JGB37-521
pan cross head_am_B18.6.7M - M2 x 0.4 x 25 Type I Cross Recessed PHMS --25N
pan cross head_am_B18.6.7M - M2 x 0.4 x 25 Type I Cross Recessed PHMS --25N001
pan cross head_am_B18.6.7M - M2 x 0.4 x 25 Type I Cross Recessed PHMS --25N002
Fixtures001

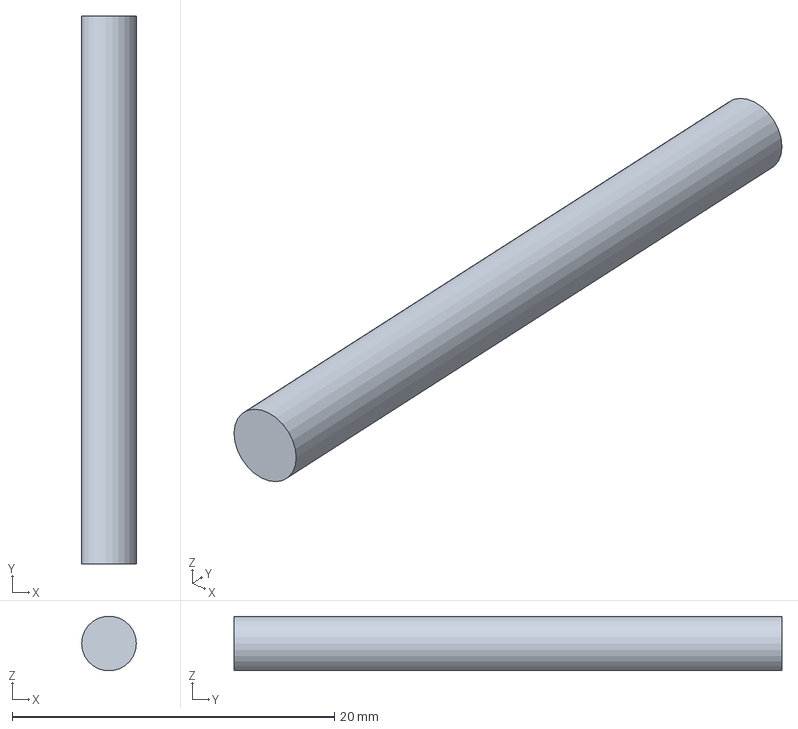
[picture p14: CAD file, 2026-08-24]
cad files/print files/track_pin.3mf
3.40 x 34.0 x 3.38 mm

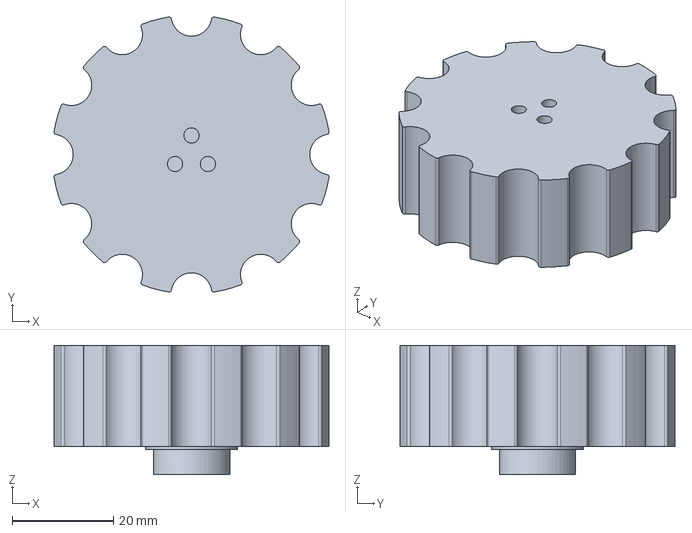
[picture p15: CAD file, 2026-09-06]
cad files/sprocket_freewheeling.FCStd
54.3 x 54.3 x 25.5 mm

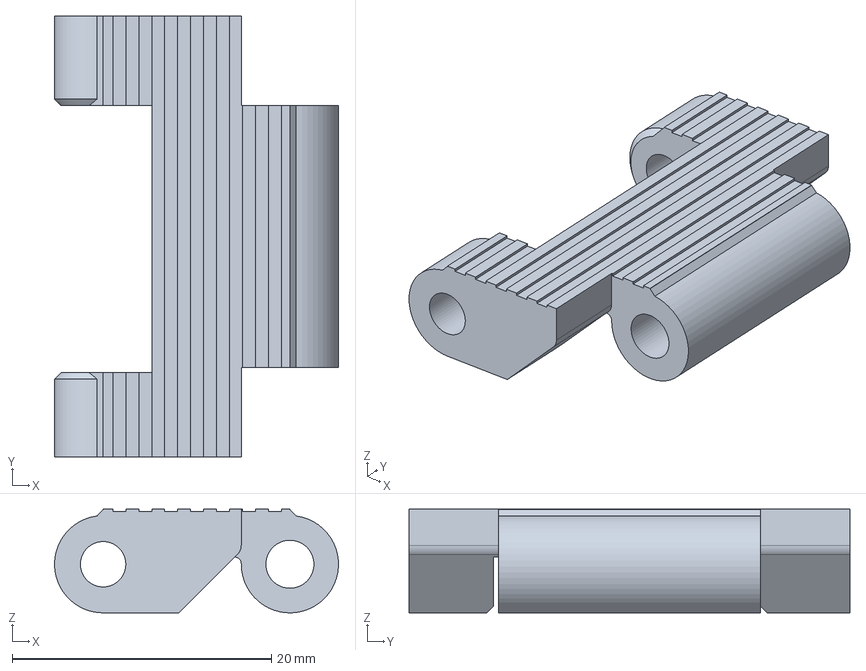
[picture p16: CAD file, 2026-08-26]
cad files/Track Link.FCStd
21.9 x 34.0 x 8.00 mm

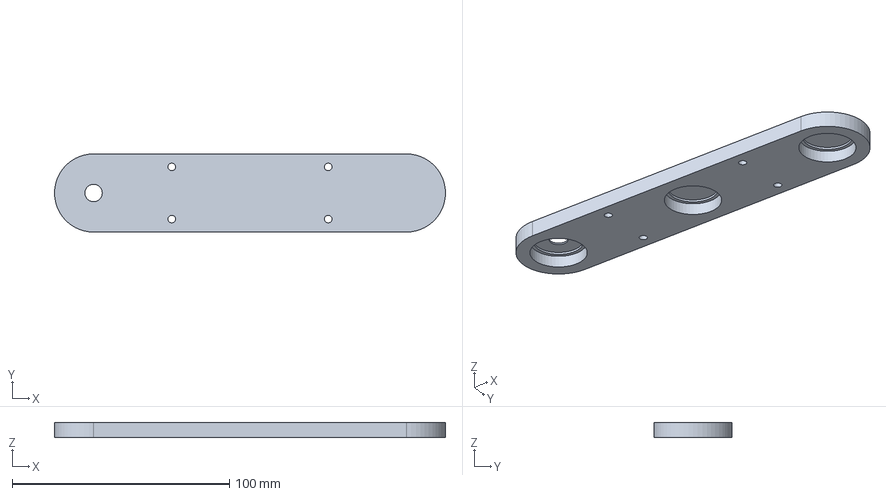
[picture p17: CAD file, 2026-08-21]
cad files/track pod inner.FCStd
180.0 x 36.0 x 7.00 mm

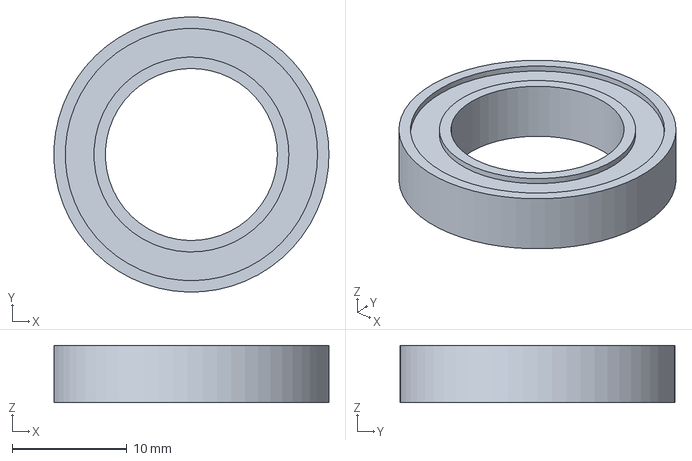
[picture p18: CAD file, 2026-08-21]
cad files/61802-2RS-bearing.FCStd
24.0 x 24.0 x 5.00 mm

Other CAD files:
cad files/full assembly.FCStd
cad files/track_pod_assembly.FCStd
cad files/track_chain_assembly.FCStd
cad files/track pod.FCStd
cad files/chassis.FCStd
cad files/track_techdraw.FCStd
cad files/print files/sprocket_driven.3mf
cad files/print files/sprocket_freewheeling.3mf
cad files/print files/track pod-inner.3mf
cad files/print files/track_link.3mf

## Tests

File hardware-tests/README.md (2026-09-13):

# hardware-tests

Standalone, breadboard-scale hardware tests for the explorer-robot sensors.
Each test is a self-contained embassy binary under `examples/` that wires one or
two sensors directly to the RP2350, independently of the main robot firmware.
This is where small "does the hardware work" checks live; the in-firmware
`task/testmode/` tasks remain the place for procedures that run inside the robot.

## Examples

| Example | What it shows |
|---|---|
| `lidar_tft_radar` | Top-down radar: 1–5 m white range rings centred on the LiDAR, one red cross per valid return at its angle/range. |
| `touch_probe` | Raw XPT2046/TSC2046-class samples alone on SPI0: logs every sample's `x`/`y`/`z1`/`z2` and the raw extents per corner, to confirm the protocol and seed calibration. |
| `touch_coexistence`  | ST7789 TFT and touch controller sharing one full-duplex SPI0 bus: draws the moving-median-filtered, calibrated touch point, with four coloured corner targets for calibration. |
| `touch_menu` | Touch-driven mock of the robot's real menu tree on the 2.8″ panel: Main Menu → submenus → placeholder leaves, a mocked System Info screen, and draggable value entry. |

Run one with (from the repository root):

```sh
cargo run -p hardware-tests --example lidar_tft_radar --release
cargo run -p hardware-tests --example touch_menu --release
```

Use `--release`: at `opt-level = 0` the framebuffer clear/draw is unusably slow.

## Wiring

The examples use the same pins as the standalone `coin-d6` and `st7789-async`
examples (which do not collide):

| Signal | RP2350 pin |
|---|---|
| LiDAR RX ← MCU TX | GPIO 12 |
| LiDAR TX → MCU RX | GPIO 13 |
| LiDAR power MOSFET gate (active-high) | GPIO 15 |
| SPI SCK (TFT + touch, shared) | GPIO 18 |
| SPI MOSI (TFT + touch, shared) | GPIO 19 |
| SPI MISO (TFT + touch, shared) | GPIO 16 |
| TFT CS | GPIO 17 |
| TFT DC/RS | GPIO 26 |
| TFT RST | GPIO 27 |
| TFT BLK | GPIO 20 |
| Touch CS | GPIO 21 |
| Touch IRQ (PENIRQ, active-low) | GPIO 22 |

> The LiDAR power gate is **GPIO 15** here (the standalone-example pin), not the
> robot firmware's GPIO 26 — GPIO 26 is the TFT DC pin on this wiring.

> Panel notes (2.8″ 240×320, measured on the bench): the display is
> **RGB-ordered** (`ColorOrder::Bgr` swaps red and blue, so the examples here
> use `ColorOrder::Rgb`), and the touch calibration measured from the coexistence
> corner targets is recorded as `touch_async::Calibration::MEASURED`.

## Calibrating the touch panel

Touch calibration maps raw counts onto the 320 × 240 framebuffer.
`touch_coexistence` draws four coloured targets at known framebuffer
coordinates, inset 12 px from the edges, so a raw reading can be paired with an
exact pixel:

| Target | Colour | Framebuffer |
|---|---|---|
| top-left | red | (12, 12) |
| top-right | green | (307, 12) |
| bottom-right | blue | (307, 227) |
| bottom-left | yellow | (12, 227) |

To (re-)measure the panel:

1. Flash `touch_coexistence` and, for each target, press and hold it, noting the
   logged `raw x=… y=…` (ignore the `pixel` values while calibrating).
2. Average the readings per edge: `raw_x_left` from red+yellow, `raw_x_right`
   from green+blue, `raw_y_top` from red+green, `raw_y_bottom` from blue+yellow.
3. Extrapolate the 12 px inset out to the framebuffer edges, with `W = 320`,
   `H = 240`, `INSET = 12`, `FAR_X = W-1-INSET = 307`, `FAR_Y = H-1-INSET = 227`:

   ```text
   x1 = raw_x_left - INSET * (raw_x_right  - raw_x_left)  / (FAR_X - INSET)
   x2 = x1 + (W - 1) * (raw_x_right - raw_x_left) / (FAR_X - INSET)

   y1 = raw_y_top  - INSET * (raw_y_bottom - raw_y_top)   / (FAR_Y - INSET)
   y2 = y1 + (H - 1) * (raw_y_bottom - raw_y_top) / (FAR_Y - INSET)
   ```

4. Record the four endpoints as `touch_async::Calibration::MEASURED` in
   `touch-async/src/calibration.rs`.

`Calibration::REFERENCE` keeps the vendor board's uncalibrated values and is what
`Calibration::default()` returns; `touch_coexistence` uses `Calibration::MEASURED`.

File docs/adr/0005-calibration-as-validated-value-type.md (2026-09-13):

# Calibration is a validated value type

`Calibration` maps raw touch counts onto the screen's pixel grid, and that
mapping is arithmetic with real preconditions: each axis is linearly interpolated
by dividing by the difference between its two raw endpoints, and the result is
clamped to `0..width - 1` (or `0..height - 1`). Equal endpoints make the divisor
zero, and a non-positive dimension makes the clamp range invalid; both panic. The
struct shipped with public fields, so any caller could construct such a value and
nothing documented the panic contract.

**Status:** accepted

**Considered Options**

- **Public fields plus a documented panic contract:** the minimal change, but it
  leaves the invalid states representable and merely warns about them.
- **Private fields plus a panicking `const fn new` only:** keeps shipped
  calibrations const-constructible, but gives a runtime-measured calibration no
  way to reject a bad value without panicking.
- **Private fields plus a panicking `const fn new` and a fallible `try_new`:**
  chosen. The const path keeps the shipped constants const; the fallible path
  lets runtime callers handle a bad measurement.

**Decision**

- The six fields are private. Construction goes through `Calibration::new`
  (`const`, asserts, documents `# Panics`) or `Calibration::try_new` (returns
  `Result<Self, CalibrationError>`).
- The enforced invariants are `width >= 1`, `height >= 1`, and distinct raw
  endpoints on each axis (`x1 != x2`, `y1 != y2`).
- Endpoint magnitudes are deliberately **not** bounded. Raw endpoints are
  legitimately extrapolated from the inset calibration targets, so limiting them
  to the 12-bit raw range would reject valid calibrations. `to_pixels` instead
  widens its intermediate arithmetic to `i64`, so no endpoint values that fit an
  `i32` can overflow it.
- `CalibrationError` has two variants — `NonPositiveDimension` and
  `DegenerateAxis` — and derives the crate's error shape
  (`Debug, Clone, Copy, PartialEq, Eq`). It does not implement `Display` or
  `core::error::Error`, matching `touch-async::Error`.
- `Calibration::REFERENCE` and `Calibration::MEASURED` are built through `new`,
  so an invalid shipped constant fails the build.
- `Default` remains `Calibration::REFERENCE` (the spec's shipped reference
  defaults), documented as vendor values for first bring-up only; this panel uses
  `MEASURED`.

**Consequences**

- Callers can no longer build a `Calibration` with a struct literal, and cannot
  read the endpoints back: the fields are private and there are no accessors
  until a persistence or logging caller needs them.
- `to_pixels` has no panic path for any value constructible through the public
  API, so the "public API can panic on a division by zero or an invalid clamp
  range" review finding is closed.
- The const constructor keeps both shipped calibrations as compile-time
  constants.

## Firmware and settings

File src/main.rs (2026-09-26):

//! explorer-robot v3 firmware entry point
//!
//! Core0 hosts orchestrator, motor driver, encoders, battery monitor,
//! RGB LED, panel (TFT + touch), VL53L0X stub, flash storage, UI, testmode,
//! autonomous mode controller, and startup.
//!
//! Core1 hosts the real COIN-D6 `LiDAR` driver task, powered on demand.

#![no_std]
#![no_main]

use defmt::info;
use defmt_rtt as _;
use embassy_executor::{Executor, Spawner};
use embassy_rp::{
    adc::{Adc, Channel, Config as AdcConfig, InterruptHandler as AdcInterruptHandler},
    bind_interrupts,
    block::ImageDef,
    config::Config,
    dma::InterruptHandler as DmaInterruptHandler,
    flash::{Async, Flash},
    gpio::{Level, Output, Pull},
    i2c::{Config as I2cConfig, I2c, InterruptHandler as I2cInterruptHandler},
    multicore::{Stack, spawn_core1},
    peripherals::{
        ADC, DMA_CH0, DMA_CH1, DMA_CH2, DMA_CH3, DMA_CH4, DMA_CH5, DMA_CH6, DMA_CH7, FLASH, I2C0, PIN_0, PIN_1, PIN_2,
        PIN_3, PIN_4, PIN_5, PIN_6, PIN_7, PIN_8, PIN_9, PIN_10, PIN_11, PIN_12, PIN_13, PIN_14, PIN_15, PIN_16,
        PIN_17, PIN_18, PIN_19, PIN_20, PIN_21, PIN_26, PIN_27, PIN_40, PIO1, PWM_SLICE0, PWM_SLICE1, PWM_SLICE3,
        PWM_SLICE4, SPI0, UART0, UART1,
    },
    pio::{Common, InterruptHandler as PioInterruptHandler, Pio, StateMachine},
    pio_programs::pwm::{PioPwm, PioPwmProgram},
    pwm::{Config as PwmConfig, InputMode, Pwm},
    spi::{self, Spi},
    uart::{self, BufferedUart, InterruptHandler as UartInterruptHandler, Uart},
};
use embassy_sync::{blocking_mutex::raw::CriticalSectionRawMutex, mutex::Mutex};
use panic_probe as _;
use static_cell::StaticCell;

use crate::task::io::panel::PanelPins;

mod system;
mod task;

// ── Crate-level type alias ────────────────────────────────────────────────────

/// Shared I2C0 bus protected by a critical-section mutex.
///
/// Reserved for the VL53L0X rangefinder on core0.
pub type I2cBusShared = Mutex<CriticalSectionRawMutex, I2c<'static, I2C0, embassy_rp::i2c::Async>>;

// ── Interrupt bindings ─────────────────────────────────────────────────────────

bind_interrupts!(pub struct Irqs {
    I2C0_IRQ => I2cInterruptHandler<I2C0>;
    ADC_IRQ_FIFO => AdcInterruptHandler;
    PIO1_IRQ_0 => PioInterruptHandler<PIO1>;
    DMA_IRQ_0 => DmaInterruptHandler<DMA_CH0>, DmaInterruptHandler<DMA_CH1>, DmaInterruptHandler<DMA_CH2>,
        DmaInterruptHandler<DMA_CH3>, DmaInterruptHandler<DMA_CH4>, DmaInterruptHandler<DMA_CH5>,
        DmaInterruptHandler<DMA_CH6>, DmaInterruptHandler<DMA_CH7>;
    UART0_IRQ => uart::BufferedInterruptHandler<UART0>;
    UART1_IRQ => UartInterruptHandler<UART1>;
});

// ── Boot descriptor ────────────────────────────────────────────────────────────

/// Firmware image type for bootloader
#[unsafe(link_section = ".start_block")]
#[used]
pub static IMAGE_DEF: ImageDef = ImageDef::secure_exe();

// ── Core stacks & executors ────────────────────────────────────────────────────

/// Core1 stack — 16 KiB for the real COIN-D6 `LiDAR` driver task.
///
/// Budget: ~1.5 KiB point cloud + ~8 KiB UART/DMA buffers + ~4 KiB
/// frame-parser state + ~2 KiB embassy async overhead.
static mut CORE1_STACK: Stack<16384> = Stack::new();

/// Executor for core0 (orchestrator, drive, UI, sensors on I2C).
static EXECUTOR0: StaticCell<Executor> = StaticCell::new();

/// Executor for core1 (`LiDAR` driver).
static EXECUTOR1: StaticCell<Executor> = StaticCell::new();

// ── Pin structs ────────────────────────────────────────────────────────────────

/// Pins used by the TB6612FNG motor driver and motor encoders.
///
/// Two-track configuration: left PWM on GPIO 0 (slice 0), right PWM on
/// GPIO 3 (slice 1). Direction pins are direct-GPIO outputs (IN1/IN2 per
/// channel), relocated off the RP2350's fixed UART RX pins (GPIO 1/4/5)
/// to free those for the D6 `LiDAR` and AI cam UARTs. Encoders use PWM
/// input mode on slices 3 and 4.
pub struct MotorDriverPins {
    /// Left motor PWM slice + pin.
    pub left_pwm_slice: embassy_rp::Peri<'static, PWM_SLICE0>,
    pub left_pwm_pin: embassy_rp::Peri<'static, PIN_0>,
    /// Left motor forward direction pin (GPIO 8; moved off GPIO 1 to free UART0 RX).
    pub left_fwd: embassy_rp::Peri<'static, PIN_8>,
    /// Left motor backward direction pin.
    pub left_bwd: embassy_rp::Peri<'static, PIN_2>,
    /// Right motor PWM slice + pin.
    pub right_pwm_slice: embassy_rp::Peri<'static, PWM_SLICE1>,
    pub right_pwm_pin: embassy_rp::Peri<'static, PIN_3>,
    /// Right motor forward direction pin (GPIO 10; moved off GPIO 4 to free UART1 TX).
    pub right_fwd: embassy_rp::Peri<'static, PIN_10>,
    /// Right motor backward direction pin (GPIO 11; moved off GPIO 5 to free UART1 RX).
    pub right_bwd: embassy_rp::Peri<'static, PIN_11>,
    /// TB6612FNG standby pin (active high).
    pub standby: embassy_rp::Peri<'static, PIN_6>,
    /// Left encoder PWM slice + pin (input mode).
    pub enc_left_slice: embassy_rp::Peri<'static, PWM_SLICE3>,
    pub enc_left_pin: embassy_rp::Peri<'static, PIN_7>,
    /// Right encoder PWM slice + pin (input mode).
    pub enc_right_slice: embassy_rp::Peri<'static, PWM_SLICE4>,
    pub enc_right_pin: embassy_rp::Peri<'static, PIN_9>,
}

/// Pins for the common-cathode RGB status LED.
pub struct RgbLedPins {
    /// Red channel (GPIO 13).
    pub red: embassy_rp::Peri<'static, PIN_13>,
    /// Green channel (GPIO 14).
    pub green: embassy_rp::Peri<'static, PIN_14>,
    /// Blue channel (GPIO 15).
    pub blue: embassy_rp::Peri<'static, PIN_15>,
}

/// Pins for the COIN-D6 360° spinning dTOF `LiDAR`.
///
/// Runs on **core1** over a dedicated UART0 peripheral. The sensor is off at
/// boot; the driver task powers it on demand and streams scan data at 10 Hz
/// (~230 400 baud). A power MOSFET (IRLS44N) on the supply rail allows
/// firmware-controlled power cycling.
///
/// Pin choice is constrained by the RP2350's fixed UART alt-function
/// table: UART0 RX only exists on GPIO 1/13/17, all otherwise claimed
/// (motor/RGB/I2C0) except GPIO 1 after relocating the motor's
/// `left_fwd` pin. UART0 TX (GPIO 12) was already free and is now wired: the
/// driver's bound needs a readable and writable stream even though start and
/// stop are best-effort.
pub struct D6LidarPins {
    /// UART0 TX — connect to `LiDAR` RX (GPIO 12).
    pub uart_tx: embassy_rp::Peri<'static, PIN_12>,
    /// UART0 RX — connect to `LiDAR` TX (GPIO 1).
    pub uart_rx: embassy_rp::Peri<'static, PIN_1>,
    /// Power MOSFET gate (IRLS44N low-side switch, active-high, GPIO 26).
    pub power_mosfet: embassy_rp::Peri<'static, PIN_26>,
    /// UART0 peripheral instance.
    pub uart: embassy_rp::Peri<'static, UART0>,
}

/// Resources for the Grove Vision AI V2 camera module.
///
/// Runs on **core0** over a dedicated UART1 peripheral. The module runs
/// on-device ML inference (Himax `WiseEye2`) and reports results over
/// serial. A power MOSFET (IRLS44N) on the supply rail allows
/// firmware-controlled power cycling.
///
/// GPIO 25 is unavailable (hardwired to the onboard LED), so this uses
/// UART1 on GPIO 4/5 after relocating the motor's `right_fwd`/`right_bwd`
/// pins, which are the RP2350's only UART1 TX/RX pin pair besides GPIO 8/9
/// (GPIO 9 is taken by the right encoder). Full duplex (unlike the D6),
/// since the module expects host commands and returns results over the
/// same UART — hence a second DMA channel for TX.
pub struct AiCamPins {
    /// UART1 TX — connect to AI cam RX (GPIO 4).
    pub uart_tx: embassy_rp::Peri<'static, PIN_4>,
    /// UART1 RX — connect to AI cam TX (GPIO 5).
    pub uart_rx: embassy_rp::Peri<'static, PIN_5>,
    /// Power MOSFET gate (IRLS44N low-side switch, active-high, GPIO 27).
    pub power_mosfet: embassy_rp::Peri<'static, PIN_27>,
    /// UART1 peripheral instance.
    pub uart: embassy_rp::Peri<'static, UART1>,
    /// DMA channel for UART1 TX streaming.
    pub dma_tx: embassy_rp::Peri<'static, DMA_CH5>,
    /// DMA channel for UART1 RX streaming.
    pub dma_rx: embassy_rp::Peri<'static, DMA_CH4>,
}

// ── Shared bus helpers ─────────────────────────────────────────────────────────

/// Initialise the shared I2C0 bus for the VL53L0X rangefinder.
///
/// Must be called on core0 so that `I2c::new_async` enables `I2C0_IRQ` on
/// core0's NVIC. Returns a `'static` reference for sharing across tasks.
fn init_i2c_bus(
    i2c0: embassy_rp::Peri<'static, I2C0>,
    sda: embassy_rp::Peri<'static, PIN_16>,
    scl: embassy_rp::Peri<'static, PIN_17>,
) -> &'static I2cBusShared {
    static I2C_BUS: StaticCell<I2cBusShared> = StaticCell::new();

    let mut i2c_config = I2cConfig::default();
    i2c_config.frequency = 400_000;

    let i2c = I2c::new_async(i2c0, scl, sda, Irqs, i2c_config);
    I2C_BUS.init(Mutex::new(i2c))
}

/// Motor PWM configuration: 20 kHz, the TB6612FNG's sweet spot.
fn motor_pwm_config() -> PwmConfig {
    let desired_freq_hz = 20_000u32;
    let clock_freq_hz = embassy_rp::clocks::clk_sys_freq();
    #[allow(clippy::cast_possible_truncation)]
    let divider = ((clock_freq_hz / desired_freq_hz) / 65535 + 1) as u8;
    #[allow(clippy::cast_possible_truncation)]
    let period = (clock_freq_hz / (desired_freq_hz * u32::from(divider))) as u16 - 1;

    let mut cfg = PwmConfig::default();
    cfg.divider = divider.into();
    cfg.top = period;
    cfg
}

/// Encoder PWM input configuration (no divider, no phase-correct).
fn encoder_pwm_config() -> PwmConfig {
    let mut cfg = PwmConfig::default();
    cfg.divider = 1.into();
    cfg.phase_correct = false;
    cfg
}

// ── Init functions (one per subsystem) ────────────────────────────────────────

/// Spawn the orchestrator event loop.
#[allow(clippy::unwrap_used)]
fn init_orchestrate(spawner: Spawner) {
    spawner.spawn(task::orchestrate::orchestrate().unwrap());
}

/// Set up ADC-based battery voltage monitoring.
#[allow(clippy::unwrap_used)]
fn init_battery_monitoring(
    spawner: Spawner,
    adc: embassy_rp::Peri<'static, ADC>,
    // RP2350B ADC pin (ADC0). Provisional: confirm against the board's battery
    // voltage-divider wiring before first flash.
    adc_pin: embassy_rp::Peri<'static, PIN_40>,
) {
    let adc = Adc::new(adc, Irqs, AdcConfig::default());
    let battery_channel = Channel::new_pin(adc_pin, Pull::None);
    spawner.spawn(task::battery_charge_read::battery_charge_read(adc, battery_channel).unwrap());
}

/// Set up PIO-driven RGB LED (PWM on SM 0–2).
#[allow(clippy::unwrap_used)]
fn init_rgb_led(
    spawner: Spawner,
    pio_common: &mut Common<'static, PIO1>,
    sm0: StateMachine<'static, PIO1, 0>,
    sm1: StateMachine<'static, PIO1, 1>,
    sm2: StateMachine<'static, PIO1, 2>,
    rgb_pins: RgbLedPins,
) {
    let rgb_program = PioPwmProgram::new(pio_common);
    let pwm_red = PioPwm::new(pio_common, sm0, rgb_pins.red, &rgb_program);
    let pwm_green = PioPwm::new(pio_common, sm1, rgb_pins.green, &rgb_program);
    let pwm_blue = PioPwm::new(pio_common, sm2, rgb_pins.blue, &rgb_program);
    spawner.spawn(task::indicators::rgb_led_indicate::rgb_led_indicate(pwm_red, pwm_green, pwm_blue).unwrap());
}

/// Set up the TB6612FNG motor driver and encoder reader.
///
/// Spawns the motor driver task and the encoder reader task so that both
/// are running before any drive commands arrive.
#[allow(clippy::unwrap_used)]
fn init_motor_driver(spawner: Spawner, motor_pins: MotorDriverPins) {
    let pwm_cfg = motor_pwm_config();
    let pwm_left = Pwm::new_output_a(motor_pins.left_pwm_slice, motor_pins.left_pwm_pin, pwm_cfg.clone());
    let pwm_right = Pwm::new_output_b(motor_pins.right_pwm_slice, motor_pins.right_pwm_pin, pwm_cfg);

    spawner.spawn(
        task::motor_driver::motor_driver(
            pwm_left,
            pwm_right,
            motor_pins.left_fwd,
            motor_pins.left_bwd,
            motor_pins.right_fwd,
            motor_pins.right_bwd,
            motor_pins.standby,
        )
        .unwrap(),
    );

    let enc_cfg = encoder_pwm_config();
    let enc_left = Pwm::new_input(
        motor_pins.enc_left_slice,
        motor_pins.enc_left_pin,
        Pull::None,
        InputMode::RisingEdge,
        enc_cfg.clone(),
    );
    let enc_right = Pwm::new_input(
        motor_pins.enc_right_slice,
        motor_pins.enc_right_pin,
        Pull::None,
        InputMode::RisingEdge,
        enc_cfg,
    );
    spawner.spawn(task::sensors::encoders::encoder_read(enc_left, enc_right).unwrap());

    // Drive subsystem tasks: queue executor runs per-step completions;
    // the drive task coordinates intents, sensors, and motor commands.
    spawner.spawn(task::drive::drive_queue_executor().unwrap());
    spawner.spawn(task::drive::drive().unwrap());
}

/// Spawn the VL53L0X rangefinder stub task on core0.
#[allow(clippy::unwrap_used)]
fn init_vl53l0x_stub(spawner: Spawner) {
    spawner.spawn(task::sensors::vl53l0x_stub::vl53l0x_stub_task().unwrap());
}

/// Set up flash storage for calibration data persistence.
#[allow(clippy::unwrap_used)]
fn init_flash_storage(
    spawner: Spawner,
    flash: embassy_rp::Peri<'static, FLASH>,
    dma_ch: embassy_rp::Peri<'static, DMA_CH0>,
) {
    let flash = Flash::<_, Async, { 2048 * 1024 }>::new(flash, dma_ch, Irqs);
    spawner.spawn(task::io::flash_storage::flash_storage(flash).unwrap());
}

/// Initialise the on-demand testmode controller.
fn init_testing(spawner: Spawner) {
    task::testmode::init_testing(spawner);
}

/// Initialise the touch UI controller, which owns the panel.
///
/// The bus carries both the ST7789 display and the touch controller, each with
/// its own chip select and per-device configuration (ADR-0008).
fn init_ui(spawner: Spawner, panel_pins: PanelPins) {
    task::ui::init_ui(spawner, panel_pins);
}

/// Initialise the autonomous mode controller (coast-and-avoid etc.).
fn init_autonomous_mode(spawner: Spawner) {
    task::autonomous_mode::init_autonomous_mode(spawner);
}

/// Initialise the dedicated SPI0 bus and chip-select for the IMU.
///
/// Returns the SPI bus and CS pin for passing to [`init_imu`].
fn init_imu_spi(
    spi0: embassy_rp::Peri<'static, SPI0>,
    sck: embassy_rp::Peri<'static, PIN_18>,
    mosi: embassy_rp::Peri<'static, PIN_19>,
    miso: embassy_rp::Peri<'static, PIN_20>,
    cs: embassy_rp::Peri<'static, PIN_21>,
    dma_ch1: embassy_rp::Peri<'static, DMA_CH1>,
    dma_ch2: embassy_rp::Peri<'static, DMA_CH2>,
) -> (Spi<'static, SPI0, spi::Async>, Output<'static>) {
    let mut spi_config = spi::Config::default();
    spi_config.frequency = 7_000_000;
    let imu_spi = Spi::new(spi0, sck, mosi, miso, dma_ch1, dma_ch2, Irqs, spi_config);
    let imu_cs = Output::new(cs, embassy_rp::gpio::Level::High);
    (imu_spi, imu_cs)
}

/// Initialise the IMU (ICM-20948) on the dedicated SPI0 bus.
///
/// The IMU task owns the SPI bus exclusively — the `Mutex` wrapper is a
/// formality (single user, never contended) that satisfies the `SpiDevice` API.
#[allow(clippy::unwrap_used)]
fn init_imu(spawner: Spawner, spi: Spi<'static, SPI0, spi::Async>, cs: Output<'static>) {
    static SPI_BUS: StaticCell<Mutex<CriticalSectionRawMutex, Spi<'static, SPI0, spi::Async>>> = StaticCell::new();
    let spi_bus = SPI_BUS.init(Mutex::new(spi));
    spawner.spawn(task::sensors::imu::inertial_measurement_read(spi_bus, cs).unwrap());
}

/// `LiDAR` UART baud rate (230400 8N1).
const D6_LIDAR_BAUD: u32 = 230_400;
/// `BufferedUart` TX ring buffer size (start/stop commands are 4 bytes).
const D6_LIDAR_TX_BUF_LEN: usize = 16;
/// `BufferedUart` RX ring buffer size; absorbs stream data between reads.
const D6_LIDAR_RX_BUF_LEN: usize = 4096;

/// Static TX ring buffer for the `LiDAR`'s buffered UART.
static D6_LIDAR_TX_BUF: StaticCell<[u8; D6_LIDAR_TX_BUF_LEN]> = StaticCell::new();
/// Static RX ring buffer for the `LiDAR`'s buffered UART.
static D6_LIDAR_RX_BUF: StaticCell<[u8; D6_LIDAR_RX_BUF_LEN]> = StaticCell::new();

/// Bring up the COIN-D6 `LiDAR`'s buffered UART0 and spawn its task on core1.
///
/// The UART is full duplex — the driver's bound needs a readable and writable
/// stream even though start and stop are best-effort — on the reserved RX/TX pair
/// (GPIO 1 / GPIO 12). The power gate starts low, so the sensor is off at boot.
///
/// Must be called on **core1** so `UART0_IRQ` is enabled on core1's NVIC,
/// mirroring how `init_i2c_bus` must run on core0 for `I2C0_IRQ`.
#[allow(clippy::unwrap_used)]
fn init_lidar(spawner: Spawner, d6_pins: D6LidarPins) {
    let mut uart_config = uart::Config::default();
    uart_config.baudrate = D6_LIDAR_BAUD;

    let uart = BufferedUart::new(
        d6_pins.uart,
        d6_pins.uart_tx,
        d6_pins.uart_rx,
        Irqs,
        D6_LIDAR_TX_BUF.init([0u8; D6_LIDAR_TX_BUF_LEN]),
        D6_LIDAR_RX_BUF.init([0u8; D6_LIDAR_RX_BUF_LEN]),
        uart_config,
    );

    // Powered off by default; the driver asserts this only while enabled.
    let power = Output::new(d6_pins.power_mosfet, Level::Low);

    spawner.spawn(task::sensors::lidar::lidar_task(uart, power).unwrap());
}

/// Bring up the Grove Vision AI V2's UART1 peripheral (full duplex) and power MOSFET.
///
/// Full duplex, unlike the D6: the module expects host commands (e.g.
/// invoke/query) and returns inference results over the same UART.
///
/// This only brings the peripheral up — no protocol implementation yet.
/// Returns the UART and the MOSFET output for the real driver task to
/// consume once it exists.
fn init_ai_cam_uart(ai_cam_pins: AiCamPins) -> (Uart<'static, uart::Async>, Output<'static>) {
    let mut uart_config = uart::Config::default();
    uart_config.baudrate = 115_200;

    let uart = Uart::new(
        ai_cam_pins.uart,
        ai_cam_pins.uart_tx,
        ai_cam_pins.uart_rx,
        Irqs,
        ai_cam_pins.dma_tx,
        ai_cam_pins.dma_rx,
        uart_config,
    );

    // Powered off by default; the real driver drives this high to power the module.
    let power_mosfet = Output::new(ai_cam_pins.power_mosfet, embassy_rp::gpio::Level::Low);

    (uart, power_mosfet)
}
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
fn main() -> ! {
    let mut config = Config::default();
    config.clocks = embassy_rp::clocks::ClockConfig::system_freq(150_000_000)
        .unwrap_or_else(|e| defmt::panic!("Failed to configure system clocks {}", e));
    let p = embassy_rp::init(config);

    info!("explorer-robot v3 booting...");

    // ── PIO1: RGB LED (SM 0–2) ─────────────────────────────────────────────
    let Pio {
        common: mut pio1_common,
        sm0: pio1_sm0,
        sm1: pio1_sm1,
        sm2: pio1_sm2,
        ..
    } = Pio::new(p.PIO1, Irqs);

    // ── Pin structs ────────────────────────────────────────────────────────
    let rgb_pins = RgbLedPins {
        red: p.PIN_13,
        green: p.PIN_14,
        blue: p.PIN_15,
    };

    let motor_pins = MotorDriverPins {
        left_pwm_slice: p.PWM_SLICE0,
        left_pwm_pin: p.PIN_0,
        left_fwd: p.PIN_8,
        left_bwd: p.PIN_2,
        right_pwm_slice: p.PWM_SLICE1,
        right_pwm_pin: p.PIN_3,
        right_fwd: p.PIN_10,
        right_bwd: p.PIN_11,
        standby: p.PIN_6,
        enc_left_slice: p.PWM_SLICE3,
        enc_left_pin: p.PIN_7,
        enc_right_slice: p.PWM_SLICE4,
        enc_right_pin: p.PIN_9,
    };

    // D6 LiDAR — dedicated buffered UART0 on core1, powered on demand.
    let d6_pins = D6LidarPins {
        uart_tx: p.PIN_12,
        uart_rx: p.PIN_1,
        power_mosfet: p.PIN_26,
        uart: p.UART0,
    };

    // Grove Vision AI V2 — dedicated UART1 on core0 (reserved, not yet driven).
    let ai_cam_pins = AiCamPins {
        uart_tx: p.PIN_4,
        uart_rx: p.PIN_5,
        power_mosfet: p.PIN_27,
        uart: p.UART1,
        dma_tx: p.DMA_CH5,
        dma_rx: p.DMA_CH4,
    };

    // ── Core1: LiDAR driver ─────────────────────────────────────────────────
    #[allow(static_mut_refs)]
    spawn_core1(p.CORE1, unsafe { &mut CORE1_STACK }, move || {
        // Initialised on core1 so UART0_IRQ is enabled on core1's NVIC.
        let executor1 = EXECUTOR1.init(Executor::new());
        executor1.run(|spawner| {
            init_lidar(spawner, d6_pins);
        });
    });

    // ── Core0: all other tasks ──────────────────────────────────────────────
    let executor0 = EXECUTOR0.init(Executor::new());
    executor0.run(move |spawner| {
        // I2C0 bus reserved for the VL53L0X rangefinder stub.
        // Initialised inside the closure so I2c::new_async enables I2C0_IRQ
        // on core0's NVIC.
        let _i2c_bus = init_i2c_bus(p.I2C0, p.PIN_16, p.PIN_17);

        // SPI bus for ICM20948 IMU
        let (imu_spi, imu_cs) = init_imu_spi(p.SPI0, p.PIN_18, p.PIN_19, p.PIN_20, p.PIN_21, p.DMA_CH1, p.DMA_CH2);

        // Shared full-duplex SPI1 bus and pins for the ST7789 panel and its
        // touch layer (ADR-0008).
        let panel_pins = PanelPins {
            spi: p.SPI1,
            sck: p.PIN_42,
            mosi: p.PIN_43,
            miso: p.PIN_44,
            tx_dma: p.DMA_CH6,
            rx_dma: p.DMA_CH7,
            display_cs: p.PIN_41,
            dc: p.PIN_45,
            rst: p.PIN_46,
            blk: p.PIN_47,
            touch_cs: p.PIN_38,
            penirq: p.PIN_39,
        };

        // UART1 for Grove Vision AI V2 — not yet consumed by any task, held
        // here until the real driver lands.
        let (_ai_cam_uart, _ai_cam_power_mosfet) = init_ai_cam_uart(ai_cam_pins);

        init_orchestrate(spawner);
        init_battery_monitoring(spawner, p.ADC, p.PIN_40);
        init_rgb_led(spawner, &mut pio1_common, pio1_sm0, pio1_sm1, pio1_sm2, rgb_pins);
        init_motor_driver(spawner, motor_pins);
        init_ui(spawner, panel_pins);
        init_vl53l0x_stub(spawner);
        init_imu(spawner, imu_spi, imu_cs);
        init_flash_storage(spawner, p.FLASH, p.DMA_CH0);
        init_testing(spawner);
        init_autonomous_mode(spawner);
        init_startup(spawner);
    });
}

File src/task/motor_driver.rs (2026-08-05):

//! Motor Driver Task
//!
//! Controls 2× JGB37-520 motors (one per track) via a single TB6612FNG driver.
//! Direction and standby pins are direct GPIO.
//!
//! # Hardware Configuration

#![allow(clippy::missing_docs_in_private_items)]
//!
//! **Left Track Motor (PWM Slice 0):**
//! - PWM: GPIO 0 (PWM0A)
//! - Direction forward: GPIO 8 (direct)
//! - Direction backward: GPIO 2 (direct)
//!
//! **Right Track Motor (PWM Slice 1):**
//! - PWM: GPIO 3 (PWM1A)
//! - Direction forward: GPIO 10 (direct)
//! - Direction backward: GPIO 11 (direct)
//!
//! **Standby pin:** GPIO 6 (direct, active high)
//!
//! # Voltage Compensation
//!
//! Scales PWM duty to maintain 6V to motors as battery drains.
//! At 8.4V battery: factor = 6.0/8.4 ≈ 0.714
//! At 6.0V battery: factor = 6.0/6.0 = 1.0
//!
//! # Calibration
//!
//! `MotorCalibration` has `left_factor` and `right_factor` multipliers (0.5–1.5).
//! Applied in `SetTracks` after voltage compensation to balance left/right tracks.
//!
//! # Architecture
//!
//! The motor driver uses a single-layer control system:
//! 1. **PWM Control**: Speed via PWM duty cycle on GPIO 0, 3
//! 2. **Direction Control**: Direct GPIO Output pins (forward/backward per track)
//! 3. **Standby**: Direct GPIO Output (active high, enable both driver halves)
//!
//! # Usage
//!
//! ```rust
//! // Drive straight at 50%
//! motor_driver::send_motor_command(MotorCommand::SetTracks { left_speed: 50, right_speed: 50 }).await;
//!
//! // Emergency stop
//! motor_driver::send_motor_command(MotorCommand::BrakeAll).await;
//! ```

use defmt::{Format, debug, info, warn};
use embassy_rp::{
    gpio::{Level, Output},
    pwm::{Pwm, SetDutyCycle},
};
use embassy_sync::{blocking_mutex::raw::CriticalSectionRawMutex, channel::Channel};
use embassy_time::{Duration, Timer};

use crate::system::state::{motion, power};

/// Target motor voltage (we compensate battery voltage down to this).
const TARGET_MOTOR_VOLTAGE: f32 = 6.0;

/// Command queue depth — enough for drive task bursts without blocking.
const COMMAND_QUEUE_SIZE: usize = 16;

/// Command channel for motor control operations.
static MOTOR_COMMAND_CHANNEL: Channel<CriticalSectionRawMutex, MotorCommand, COMMAND_QUEUE_SIZE> = Channel::new();

/// Send a motor command to the driver task.
pub async fn send_motor_command(command: MotorCommand) {
    MOTOR_COMMAND_CHANNEL.sender().send(command).await;
}

async fn receive_motor_command() -> MotorCommand {
    MOTOR_COMMAND_CHANNEL.receiver().receive().await
}

// ── Public types ─────────────────────────────────────────────────────────────────

/// Track selection (left or right side of robot).
#[derive(Debug, Clone, Copy, Eq, PartialEq, Format)]
pub enum Track {
    Left,
    Right,
}

/// Motor direction states for the TB6612FNG.
#[derive(Debug, Clone, Copy, Eq, PartialEq, Format)]
pub enum MotorDirection {
    Forward,
    Backward,
    Coast,
    Brake,
}

/// Motor control commands.
///
/// `SetTracks` is the primary calibrated command for normal operation.
/// Calibration and voltage compensation are applied.
/// `BrakeAll`, `CoastAll` are raw/safety commands.
#[derive(Debug, Clone, Copy, Format)]
pub enum MotorCommand {
    /// Set both tracks at once (calibrated + voltage compensated).
    /// Speed range: -100 (full backward) to +100 (full forward).
    SetTracks { left_speed: i8, right_speed: i8 },

    /// Brake all motors (emergency stop).
    BrakeAll,

    /// Coast all motors (freewheeling).
    CoastAll,

    /// Enable/disable the motor driver via standby pin.
    /// When disabled, all motor outputs are off (low power).
    SetAllDriversEnable { enabled: bool },

    /// Load calibration data from flash storage.
    LoadCalibration(MotorCalibration),

    /// Update both calibration factors at once.
    UpdateAllCalibration { left_factor: f32, right_factor: f32 },
}

/// Per-track calibration factors for speed balancing.
///
/// Each factor is a multiplier (0.5 to 1.5) applied to commanded speed.
/// Default is 1.0 (no correction).
#[derive(Debug, Clone, Copy, Format)]
pub struct MotorCalibration {
    pub left_factor: f32,
    pub right_factor: f32,
}

impl Default for MotorCalibration {
    fn default() -> Self {
        Self {
            left_factor: 1.0,
            right_factor: 1.0,
        }
    }
}

impl MotorCalibration {
    const MIN_FACTOR: f32 = 0.5;
    const MAX_FACTOR: f32 = 1.5;

    /// Create new calibration with specified factors (clamped to valid range).
    pub const fn new(left_factor: f32, right_factor: f32) -> Self {
        Self {
            left_factor: left_factor.clamp(Self::MIN_FACTOR, Self::MAX_FACTOR),
            right_factor: right_factor.clamp(Self::MIN_FACTOR, Self::MAX_FACTOR),
        }
    }

    /// Get calibration factor for a track.
    pub const fn get_factor(&self, track: Track) -> f32 {
        match track {
            Track::Left => self.left_factor,
            Track::Right => self.right_factor,
        }
    }

    /// Apply calibration to a commanded speed, clamping to [-100, 100].
    #[allow(clippy::cast_possible_truncation)]
    pub fn apply(&self, track: Track, speed: i8) -> i8 {
        let factor = self.get_factor(track);
        let calibrated_f32 = f32::from(speed) * factor;
        let calibrated = if calibrated_f32 >= 0.0 {
            (calibrated_f32 + 0.5) as i8
        } else {
            (calibrated_f32 - 0.5) as i8
        };
        calibrated.clamp(-100, 100)
    }

    /// Apply calibration AND voltage compensation.
    ///
    /// Two corrections in sequence:
    /// 1. Motor calibration factor (compensates for motor variations)
    /// 2. Voltage compensation factor (compensates for battery voltage)
    #[allow(clippy::cast_possible_truncation)]
    pub fn apply_with_voltage_compensation(&self, track: Track, speed: i8, voltage_comp: f32) -> i8 {
        let calibrated = self.apply(track, speed);
        let final_f32 = f32::from(calibrated) * voltage_comp;
        let result = if final_f32 >= 0.0 {
            (final_f32 + 0.5) as i8
        } else {
            (final_f32 - 0.5) as i8
        };
        result.clamp(-100, 100)
    }
}

// ── Internal types ───────────────────────────────────────────────────────────────

/// Motor direction pin pair (forward, backward) on direct GPIO.
struct MotorPins<'a> {
    forward: Output<'a>,
    backward: Output<'a>,
}
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

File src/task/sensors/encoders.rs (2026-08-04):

//! Encoder reading task for motor speed measurement
//!
//! This module provides a dedicated task for reading encoder pulse counts from both motors.
//! It separates sensing (encoder reading) from actuation (motor control), following the same
//! architecture pattern as the IMU sensor task.
//!
//! # Architecture
//!
//! The encoder task operates independently from motor control:
//! - **Sensing**: Reads encoder pulse counts at configurable intervals
//! - **Data channel**: Publishes measurements directly to the drive task via `try_send_encoder_measurement`
//! - **Commands**: Accepts control commands (start/stop/reset)
//! - **Power Management**: Can be stopped when not needed
//!
//! # Usage Patterns
//!
//! ## Basic Sampling
//! ```rust
//! // Start reading at 20Hz (50ms interval)
//! encoder_read::send_command(EncoderCommand::Start { interval_ms: 50 }).await;
//!
//! // Stop when done
//! encoder_read::send_command(EncoderCommand::Stop).await;
//! ```
//!
//! ## Delta Tracking (Measuring Motion)
//! ```rust
//! // Reset counters before a maneuver
//! encoder_read::send_command(EncoderCommand::Reset).await;
//!
//! // Perform the maneuver
//! motor_driver::send_command(SetSpeed { speed: 50 }).await;
//! Timer::after(Duration::from_secs(2)).await;
//!
//! // Read the measurement - absolute counts ARE the delta since reset
//! let measurement = wait_for_encoder_event().await;
//! let pulses = measurement.left;  // This is the delta!
//! ```
//!
//! # Encoder Hardware
//!
//! - **Type**: Single-channel pulse counting (not quadrature)
//! - **Resolution**: 8 pulses per motor revolution
//! - **Gear Ratio**: 120:1 (960 pulses per output shaft revolution)
//! - **Reading Method**: PWM input mode counting rising edges
//! - **Counter Size**: 16-bit (0-65535, wraps around)
//! - **Pins**: Left encoder GPIO 7, Right encoder GPIO 8
//!
//! # Sampling Rate Guidelines
//!
//! - **20-50 Hz** (20-50ms): Good for most control loops
//! - **10 Hz** (100ms): Power-saving mode, suitable for monitoring
//! - **100 Hz** (10ms): High-frequency feedback for precise control
//!
//! Note: Faster sampling increases CPU load but provides better time resolution

use defmt::info;
use embassy_rp::pwm::Pwm;
use embassy_sync::{blocking_mutex::raw::CriticalSectionRawMutex, channel::Channel};
use embassy_time::{Duration, Instant, Timer};

use crate::task::drive;

/// Commands for encoder reading control
#[derive(Debug, Clone, Copy)]
pub enum EncoderCommand {
    /// Start continuous encoder sampling
    ///
    /// # Parameters
    /// - `interval_ms`: Time between samples in milliseconds (e.g., 50 = 20Hz)
    Start {
        /// Sampling interval in milliseconds
        interval_ms: u64,
    },

    /// Stop encoder sampling (power saving)
    Stop,

    /// Reset all encoder counters to zero
    ///
    /// Useful for measuring deltas during maneuvers. After reset, the next
    /// measurement will show how many pulses occurred since the reset.
    Reset,
}

/// Size of the command queue for encoder control
const COMMAND_QUEUE_SIZE: usize = 16;
/// Command channel for encoder control
static ENCODER_COMMAND_CHANNEL: Channel<CriticalSectionRawMutex, EncoderCommand, COMMAND_QUEUE_SIZE> = Channel::new();

/// Send a command to the encoder task
pub async fn send_command(command: EncoderCommand) {
    ENCODER_COMMAND_CHANNEL.sender().send(command).await;
}

/// Receive a command (internal use by encoder task)
async fn receive_command() -> EncoderCommand {
    ENCODER_COMMAND_CHANNEL.receiver().receive().await
}
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

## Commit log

2026-08-05 ```text Clean up dead code and add SPI support
    Remove unused imports, functions, and fields across the codebase.
    Add SPI peripheral for future sensor communication.
    Replace queue extend method with push_all and export
    drive_queue_executor.
    Remove obsolete event handler and update perception structs with
    targeted
    dead_code annotations.
    ```
    [brake_coast.rs, coast_obstacle_avoid.rs, dispatch.rs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]
2026-08-05 Reduce VL53L0X sensor array to single floor-drop detector
    Update hardware configuration and documentation to reflect removing the
    four-sensor VL53L0X rangefinder array in favor of a single front-down
    unit for floor-drop detection. The 360° LiDAR now covers obstacle
    detection in forward, lateral, and rear arcs.
    Add a new floor-drop detection behavior with emergency braking and amber
    RGB LED indication, plus integrate the Grove Vision AI V2 camera module
    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
2026-08-06 Remove legacy agent skills and LiDAR docs
    Consolidate agent guidance into `AGENTS.md` and `docs/agents/`,
    replacing the former `.agents/skills/` directory contents. Drop
    obsolete LiDAR specification files under `misc/lidar/`.
2026-08-09 Update CONTEXT.md and README with hardware details
    Refine battery, track sprocket, and weight distribution descriptions in
    CONTEXT.md. Add bearing specification to README and clarify PCB hardware
    wording.
2026-08-21 track pod and track links and track pins designed (#2)
    A test print turns out okay so far
    [61802-2RS-bearing.FCStd, Track Link.3mf, Track Link.FCStd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]
2026-08-22 Add async ST7789 driver as workspace member (#3)
    * Add async ST7789 driver as workspace member
    Add a custom async ST7789 TFT display driver in the new
    `st7789-async` workspace member, featuring a RAM framebuffer with
    async flush over write-only SPI. Convert the project to a workspace
    and update CI to run clippy and builds across the workspace,
    including examples. Include a full-frame and partial-redraw example
    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
2026-08-23 Add coin d6 lidar driver (#4)
    Add a coin d6 lidar driver as a separate crate including example code
2026-08-23 Add hardware-tests crate for standalone sensor checks (#5)
    * Add hardware-tests crate for standalone sensor checks
    The new workspace member hosts breadboard-scale embassy binaries that
    exercise individual sensors (LiDAR, TFT) independently of the main robot
    firmware, starting with a LiDAR→TFT radar example.
    * Update LiDAR radar cross visibility comment
2026-08-24 Update track assembly with new CAD models and renders (#6)
    Refactor track assembly CAD files, consolidating track components into
    dedicated assembly files and updating sprocket models. Add assembly
    renders and export updated 3MF print files.
    [Track Link-Track_LinkTrack_Link_Body.3mf, Track Link-Track_Pin_Body.3mf, Track Link.3mf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]
2026-08-26 switch to tft (#7)
    * Update track assembly with new CAD models and renders
    * Switch display driver to ST7789 TFT on SPI1
    Replace the SSD1306 OLED display with a 240x240 ST7789 TFT panel driven
    over
    a dedicated write-only SPI1 bus. This requires moving to the RP2350B
    variant
    for additional GPIO headroom.
    Update the display interface from 4 lines x 20 characters to 14 lines x
    26
    characters, adjusting all text rendering constants and supporting code
    accordingly. Also remove an unnecessary async qualifier from t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
    [Track Link-Track_LinkTrack_Link_Body.3mf, Track Link.FCStd, explorer-robot print project.3mf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]
2026-09-06 Update chassis CAD files and progress checklist (#8)
    * Update chassis CAD files and progress checklist
    - Add motor mount STL and attribution files
    - Update chassis and bracket FreeCAD designs
    - Mark chassis, D6 lidar, and TFT driver tasks complete
    - Move print files into dedicated directory
    - Remove outdated track pod files
    * correction needed for sprockets
    * upd readme
    * upd readme
    [JGB37-520.STEP, Motor mount.stp, Track Link-Track_LinkTrack_Link_Body.3mf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]
2026-09-13 Assembly (#9)
    * chore: stop tracking FreeCAD backup files (*.FCBak)
    * docs: document assembly with parts list, tips, and images
    * chore: reorganize print files with clean names
    [chassis-Chassis MainpartPad004.3mf, chassis-Chassis MainpartPad006.3mf, chassis-Chassis MainpartPocket010.3mf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]
2026-09-13 Add async touch driver for the touch-capable 2.8" TFT (#10)
    * Add async touch driver for the touch-capable 2.8" TFT
    Introduce the `touch-async` workspace crate: a no_std, HAL-agnostic driver for the unmarked XPT2046/TSC2046-class controller on the panel touch header. `read()` performs one chip-select-asserted X/Y/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
    Bench bring-up lives in `hardware-tests`: `touch_probe` characterises the controller (confirming the protocol and the previously unproven Z channels) and captures raw c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
2026-09-13 Add touch_menu hardware test example (#11)
    * Add touch_menu hardware test example
    Adds a bench example that renders the robot's menu tree on the
    2.8" panel and drives it entirely by touch, with a mocked System Info
    screen and draggable value entry. Also documents it in the
    hardware-tests README and corrects the lidar_tft_radar angle comment
    to explain the negated plot offsets.
    * Add mirrored_x calibration helper for horizontally mirrored displays
    Replace touch_menu's hand-copied X-swapped calibration with
    Calibration::MEASURED.mirrored_x(), so a re-measurement of MEASURED
    flows through instead of drifting.
    Also end touch gestures only when PENIRQ goes high rather than on a
    first Ok(None)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
    [calibration.rs]
2026-09-20 Integrate hardware in firmware (#12)
    * Add ADRs 0006–0011 and revise context for new inputs, display, and LiDAR
    Replace the dedicated write-only display bus and text-only UI with a
    shared full-duplex SPI1 bus carrying the graphics ST7789 panel and the
    resistive touch controller. Retire the EC11 rotary encoder, making touch
    the sole operator input, and return its GPIOs to the spare pool.
    Add ADR-0006 rejecting optical flow and ADR-0007 defining the odometry
    architecture: encoder and IMU dead reckoning corrected by tilt-gated
    scan-to-map matching. Power the LiDAR on demand (ADR-0010) and store
    no-return bins as `Option<f32>` so dropouts are neither obstacles nor
    clear angles (ADR-0011).
    U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
    [basic_motor.rs, calibration.rs, coast_obstacle_avoid.rs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]
2026-09-26 Replace LiDAR lease with enable/disable commands (#13)
    * Replace LiDAR lease with enable/disable commands
    A mode now enables the sensor when it needs perception and disables it
    when done, rather than acquiring and releasing a ref-counted lease. The
    LiDAR task owns the power lifecycle and keeps the driver for the whole
    runtime; readiness is polled via the lock-free status.
    This supersedes the ownership paragraph of ADR-0010 (see ADR-0017) and
    adds ADR-0018 documenting why the cloud grid stays 1.0°, wider than the
    sensor's native 0.9° spacing, so an empty slot always means a measured
    no-return rather than a sampling hole.
    * Clarify LiDAR failure latch reset with status publish
    The task n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
    [coast_obstacle_avoid.rs, lib.rs, lidar.rs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]
2026-11-01 Circuit design (#14)
    * Add KiCad project for explorer-robot with JLCPCB design rules
    - Create schematic for RP2354B power circuitry (regulator, decoupling)
    - Add JLCPCB 4-layer 1oz design rule file
    - Ignore KiCad backup, cache, and local state files
    * Ignore KiCad PCB lock files
    * add step files from rp ref design as assets
    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
2026-11-08 External connector integration (#15)
    * started integration, using wayfinder skill. resolved first wayfinder
    tickets and introduced first esp32-c3 subproject.
    * cintinued wayfinder
    * Add ADRs for link-loss failsafe, Wi-Fi setup, and pairing
    * Establish three-workspace build layout per ADR-0040
    Split the PC side into a host workspace at `remote/`, add the
    `remote-protocol`, `remote-link`, `bridge-net` and `remote-daemon`
    skeletons, wire the Bridge to the shared crates by path, and split CI
    into robot, bridge and remote jobs.
    * Add claim-slot crate for one Active Claim state (ticket 01)
    * Add Continuous Drive drive intent (ticket 07)
    * Add Active Claim API to task/procedure (ticket 02)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
2026-11-08 Implement the robot Link integration (#17)
    * Implement the robot Link integration
    - Add the link-state model crate and host tests.
    - Own UART1, Link Port power and presence in a core0 Link Task with Enable/Disable and a TRNG Boot Id.
    - Publish the six Streams and forward the curated Events.
    - Handle remote start/stop, catalogue/status, the queue-shaped drive job and the Deadman failsafe.
    - Add the Link screen, fixed-slot header indicator and Bridge Control actions.
    * Cover link-state in CI and apply nightly formatting
    The robot CI job now runs the link-state host tests; nightly rustfmt normalized the two new import groups.
    * Address PR #17 review comments
    - Fit or clip long header title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
2026-11-09 Update versions and some polishing (#18)
    * Unify all three workspaces on Rust 1.99.1 and move the robot to embassy master, documenting why the Bridge stays on released embassy-net until xarxa-driver aligns.
    * Fix the standards review findings by amending the affected ADRs, correcting the superseded toolchain text, and removing dangling local-tracker paths.
    * Rename the UART and power helper structs and collapse the three-step teardown, keeping the ADR-0023 power sequence unchanged.
    * Refresh the repository READMEs and doc comments so each part explains its role and links upward, and remove ticket references that point outside the repository.
2026-11-10 introduce first remote app (#19)
    * docs: record the remote app drive policy and glossary terms
    * fix(remote): accept loopback pairing after the client hello
    A loopback peer skips the LAN auth gate, so its pair message reached the
    steady-state loop and was dropped. Store it through the token gate; the host
    already files it under the last discovered device and retries the Session on
    the next Beacon. Adds the hello -> pair -> stored -> connected host-chain test.
    * feat(app): add the Remote App shell, transport and first live values
    Serve a static ES-module SPA at /, derive the /ws URL from the page origin,
    send the client hello and a 1 Hz heartbeat, surface 4401/4426/1001 and
    reconnect with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
2026-11-10 Board bringup (#20)
    * Align .text with its linker alignment
    * Use PWM channel B for the right motor
    * Make the floor-drop stub opt-in
    * Fix ICM-20948 SPI init and add Axis9 debug validation
    - Wait the datasheet reset time before polling PWR_MGMT_1.
    - Enable SPI mode and probe WHO_AM_I after a failed init.
    - Add the imu_debug feature with 1 Hz orientation and raw sensor logs.
    - Reject non-unit quaternions and identity/no-compass packets.
    * Address PR #20 review comments
    Queue IMU commands in order so a mode change issued immediately before Start is not overwritten by the single-slot signal, keeping distance driving in Axis6. Also keep raw accel, gyro, and mag fields flowing when a DMP q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
2026-11-13 Update icm 20948 (#21)
    * Migrate to icm20948-rs 0.3.0
    Take the driver's SPI bring-up path: init_spi() performs the soft reset, restores SPI mode with write-only accesses, wakes the device and verifies WHO_AM_I, so the local ResetDelay workaround for the 1 ms post-reset poll is gone. A failed attempt still probes WHO_AM_I to tell an absent chip from a failed reset.
    Drive the DMP from the validated DmpSampleRate::Hz112 (112.5 Hz actual) and poll the FIFO every 4 ms. Reads now go through a caller-owned DmpFifoReader that keeps a partial packet across polls, recreated per Start and cleared on a mode change, config restore and FIFO reset so stale framing cannot leak between sessions; packet.raw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
2026-11-14 Harden LiDAR bring-up and align docs with current behavior (#22)
    * Harden LiDAR bring-up and size core1 for the task
    - Bound the device-info probe and tolerate its failure; warm-up is the proof that scans flow. The frame is emitted before the UART exists and a streaming device does not resend it.
    - Gate the LiDAR power/UART and room-scan intent logs, and the boot reset cause, behind telemetry_logs.
    - Give the core1 LiDAR task a 64 KiB stack and compile the firmware package at dev opt-level 1; the measured LiDAR frame is ~29 KiB in both dev-opt1 and release.
    - Disable incremental release builds.
    * Document current LiDAR power and harness state
    - Record the measured ~320 mA baseline with th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
2026-11-14 Webapp lidar visuals improvement (#23)
    * docs: define Occlusion Shadow and record ADR-0046
    * feat(remote-app): infer and shade LiDAR occlusion shadows
    * feat(remote-app): draw occlusion edges and break the fake chord
    * feat(remote-app): mute stale shadows and describe them accessibly
    * refactor(remote-app): address occlusion shadow review findings
    * feat(remote-app): shade the exact unseen complement
    * feat(remote-app): dot the No Return notch boundaries
    * feat(remote-app): add a radar legend and trim the notch rays
    * fix(remote-app): close the No Return notch at its returns
    * docs: align the Occlusion Edge with the notch chord
    * refactor(remote-app): harden the exact unseen comple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
